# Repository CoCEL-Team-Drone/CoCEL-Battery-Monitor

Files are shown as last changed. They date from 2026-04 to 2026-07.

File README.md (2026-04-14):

# CoCEL LiPo Battery Monitor



**A high-current LiPo battery monitor with individual cell voltage sensing**

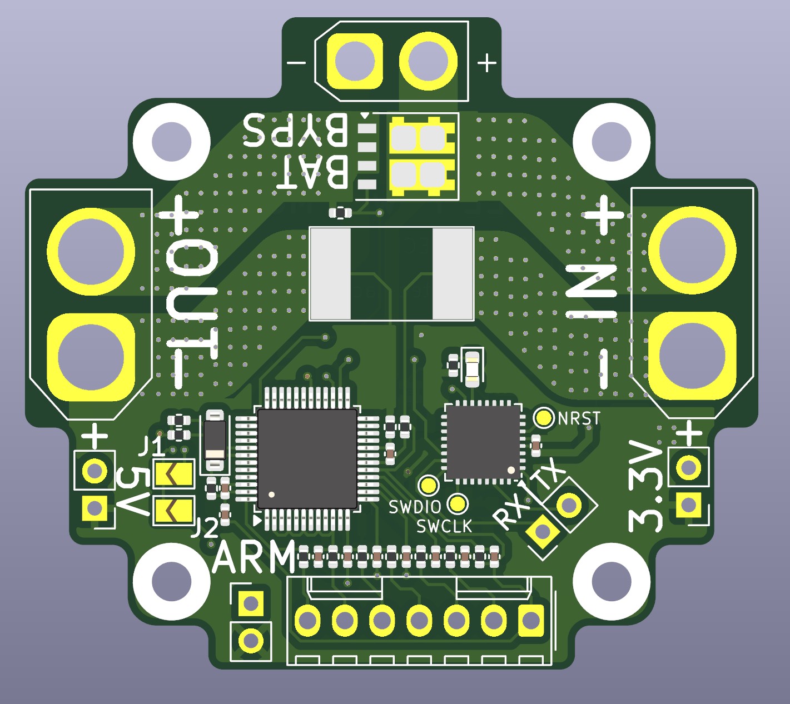
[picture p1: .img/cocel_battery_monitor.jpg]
CoCEL Battery Monitor Image


[!IMPORTANT] 
This project is currently under development! Especially cell voltage monitoring circuit. Please stay tuned for future updates.

The CoCEL LiPo Battery Monitor is a dedicated power management and monitoring solution for multicopters. It measures total pack voltage, discharge current, and individual cell voltages, interfacing with a FC via UART.

## 1. Core Specifications

### Power
- **Voltage:** 4s~6s LiPo (14.8 V ~ 25.2 V)
- **Current:** 200 A continuous
- **Output Cutoff:** Main power output can be cut off via a physical arming switch (shorting pins) or via UART commands
- **Aux Power Output:**
    - 3.3 V (3 A)
    - 5 V (3 A)
    - Input Bypass: Dedicated power rail for an SBC (remains active even when the main output is cut off)

### Connectivity
- **Interfaces:** 
    - **Communication:** 1x UART
    - **Visual Feedback:** 1x Diagnostic LED
    - **Firmware update:** Test points are used for firmware updates (SWDIO, SWCLK, NRST).

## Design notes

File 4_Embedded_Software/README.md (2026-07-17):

# Embedded Software
Implemented by Sanghyun Park and Eunseon Choi.

## API
### Overview
1. System initialization
2. BQ initialization
3. Ready for sensing

### Input
```
type def struct
{
    int32_t type;
    int32_t data_1;
    int32_t data_2;
    int32_t data_3;
}UartReceiveData;
```
- Example  
`printf '1 4 10 1\n' > /dev/ttyACM0`

### Output
```
typedef struct
{
	uint32_t timestamp;
	uint32_t read_out_time;
	int16_t status;
	uint16_t data_1;
	uint16_t data_2;
	uint16_t data_3;
	uint16_t data_4;
	uint16_t data_5;
	uint16_t data_6;
	uint16_t data_7;
	int16_t data_etc_1;
	int16_t data_etc_2;
}UartTransmitData;
```
- Example  
`1000,5,0,2453,3534,4353,3452,1379,997,234`

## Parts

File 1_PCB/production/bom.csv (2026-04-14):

Designator | Footprint | Quantity | Value | LCSC Part #
C1, C2, C3, C4, C5, C6, C7 | 0402 | 7 | 0.22uF
C10, C14 | 0402 | 2 | 0.1uF
C15, C17, C22, C23 | 0603 | 4 | 0.1uF
C16, C21 | 1210 | 2 | 10uF
C18, C24 | 0402 | 2 | 6.8nF
C19, C20, C25, C26 | 1210 | 4 | 22uF
C8 | 0402 | 1 | 1uF
C9 | 0402 | 1 | 0.47uF
D1 | D_SOD-123 | 1 | S1AFL
D2 | 0603 | 1 | LED
JP1, JP2 | SolderJumper-2_P1.3mm_Open_TrianglePad1.0x1.5mm | 2 | Jumper_2_Small_Open
L1 | L_7.3x7.3_H4.5 | 1 | 4.7uH
L2 | L_7.3x7.3_H4.5 | 1 | 3.3uH
Q1 | ST_PowerFLAT-6L_5x6mm_P1.27mm | 1 | STL325N4LF8AG
R1, R2, R3, R4, R5, R6, R7 | 0402 | 7 | 47
R10, R11, R22, R8 | 0402 | 4 | 100
R12 | 3920 | 1 | 0.001
R13, R17, R21, R26, R27 | 0402 | 5 | 10k
R14 | 0402 | 1 | 430k
R15 | 0402 | 1 | 82k
R18 | 0402 | 1 | 6.8k
R19 | 0402 | 1 | 75k
R20 | 0402 | 1 | 24k
R9 | 0402 | 1 | 1M
U1 | TQFP-48_7x7mm_P0.5mm | 1 | BQ76942
U2 | QFN-32-1EP_5x5mm_P0.5mm_EP3.45x3.45mm | 1 | STM32G031K8Ux
U3, U4 | HTSOP-8-1EP_3.9x4.9mm_P1.27mm_EP2.4x3.2mm | 2 | BD9E302EFJ

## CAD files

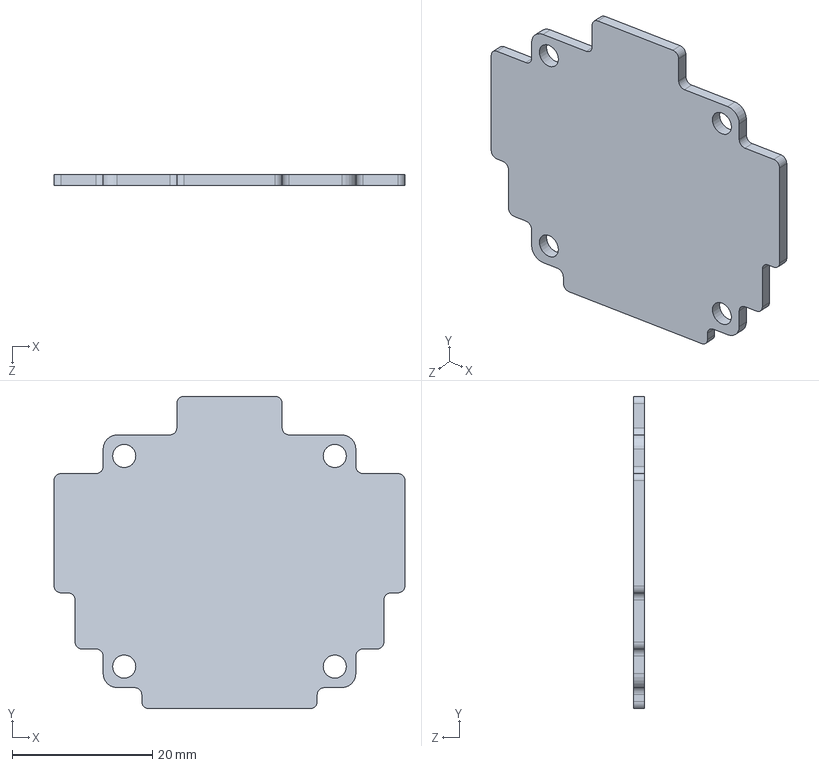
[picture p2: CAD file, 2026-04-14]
2_CAD/CoCEL_PowerMonitir_PCB.SLDPRT
50.0 x 44.5 x 1.60 mm

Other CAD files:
2_CAD/CoCEL_PowerMonitir_PCB.DXF

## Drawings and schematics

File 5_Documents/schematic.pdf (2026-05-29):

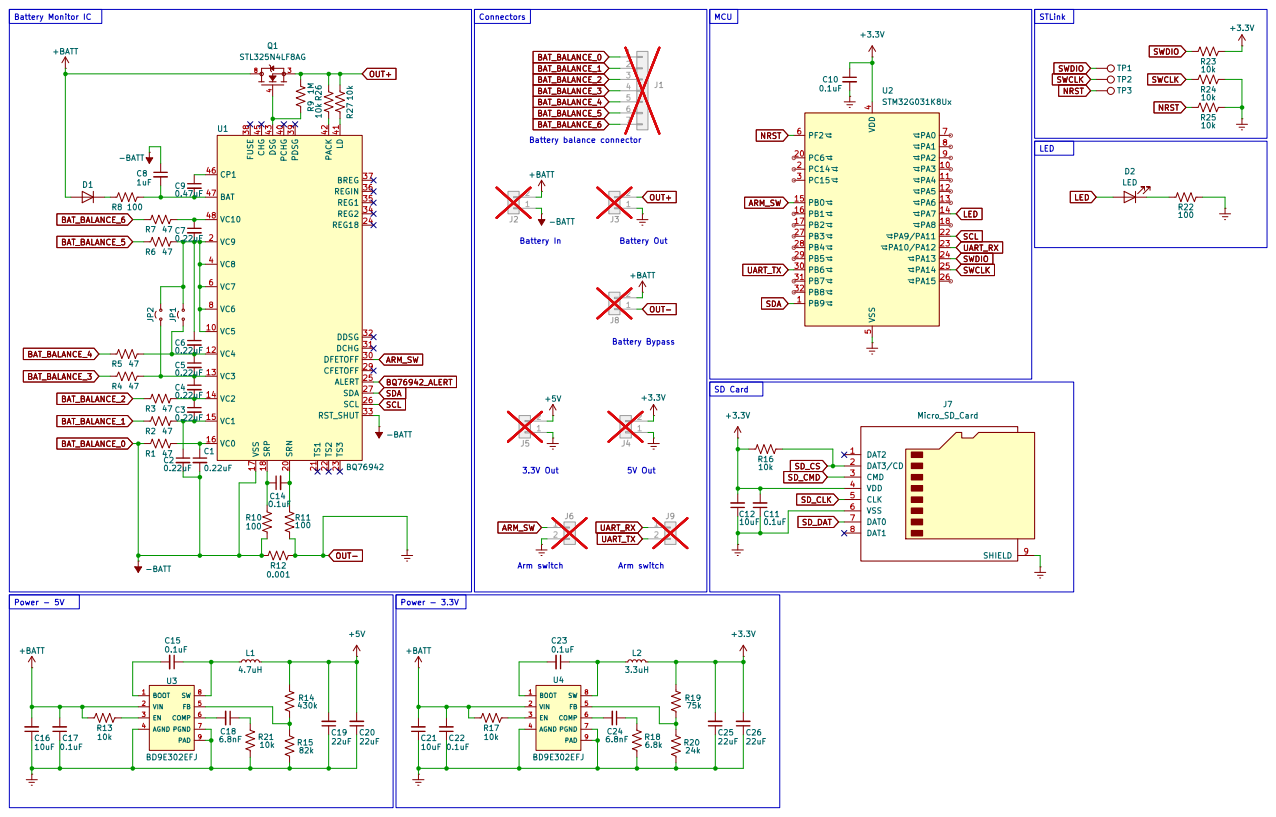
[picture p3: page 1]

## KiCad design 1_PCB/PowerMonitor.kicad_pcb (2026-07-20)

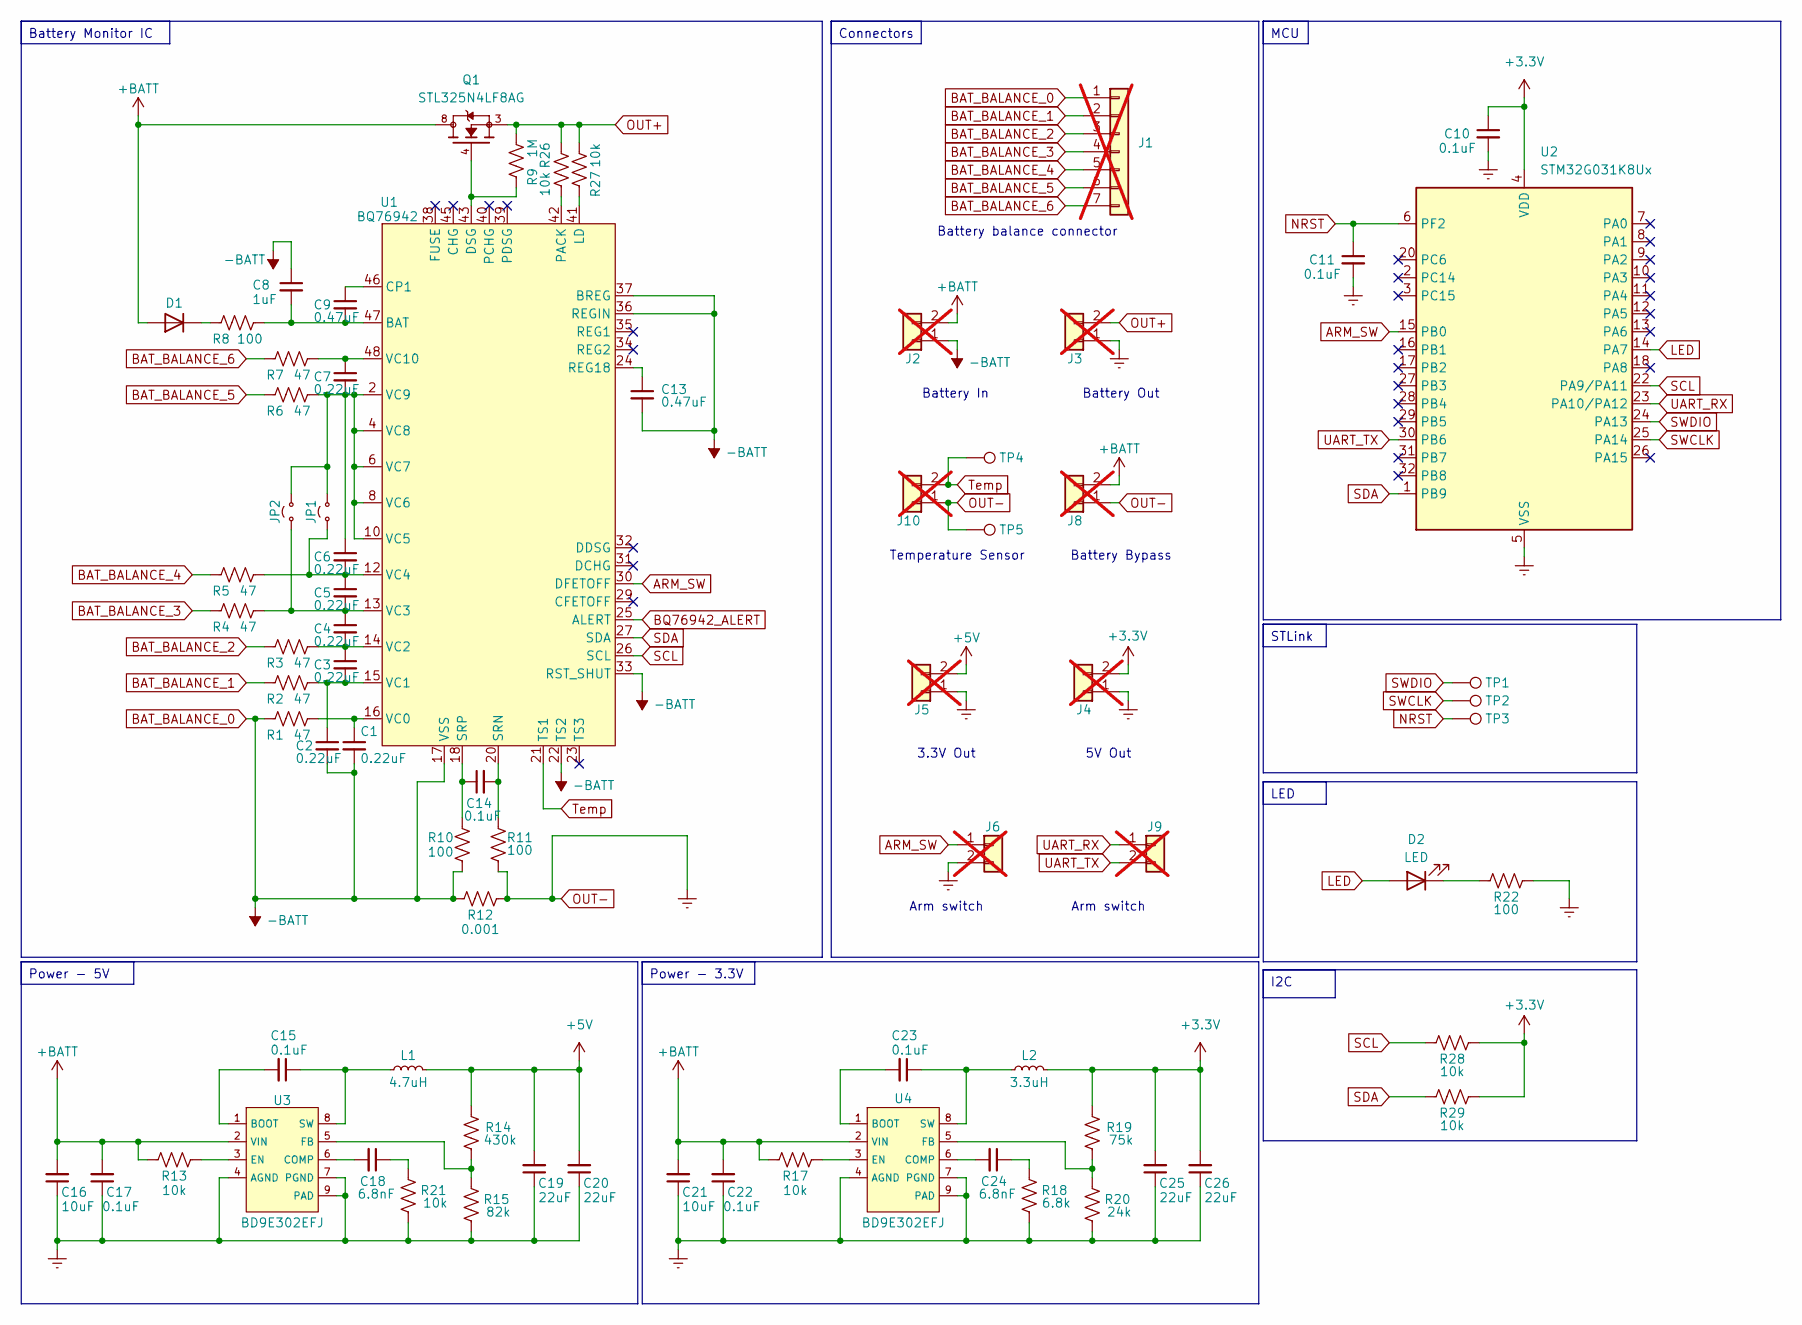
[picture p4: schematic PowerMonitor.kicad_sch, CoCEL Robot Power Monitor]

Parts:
C1, C2, C3, C4, C5, C6, C7: 0.22uF; C_0402_1005Metric
C8: 1uF; C_0402_1005Metric
C9, C13: 0.47uF; C_0402_1005Metric
C10, C11, C14: 0.1uF; C_0402_1005Metric
C15, C17, C22, C23: 0.1uF; C_0603_1608Metric
C16, C21: 10uF; C_1210_3225Metric
C18, C24: 6.8nF; C_0402_1005Metric_Pad0.74x0.62mm_HandSolder
C19, C20, C25, C26: 22uF; C_1210_3225Metric
D1: S1AFL; D_SOD-123
D2: LED; LED_0603_1608Metric
J1: Conn_01x07; Molex_KK-254_AE-6410-07A_1x07_P2.54mm_Vertical; not fitted
J2: Conn_01x02; AMASS_XT60-M_1x02_P7.20mm_Vertical; not fitted
J3: Conn_01x02; AMASS_XT60-F_1x02_P7.20mm_Vertical; not fitted
J4, J5, J6, J9, J10: Conn_01x02; PinHeader_1x02_P2.54mm_Vertical; not fitted
J8: Conn_01x02; AMASS_XT30U-F_1x02_P5.0mm_Vertical; not fitted
JP1, JP2: Jumper_2_Small_Open; SolderJumper-2_P1.3mm_Open_TrianglePad1.0x1.5mm
L1: 4.7uH; L_7.3x7.3_H4.5
L2: 3.3uH; L_7.3x7.3_H4.5
Q1: STL325N4LF8AG; ST_PowerFLAT-6L_5x6mm_P1.27mm
R1, R2, R3, R4, R5, R6, R7: 47; R_0402_1005Metric
R8, R10, R11, R22: 100; R_0402_1005Metric
R9: 1M; R_0402_1005Metric
R12: 0.001; R_3920_10052Metric
R13, R17, R21, R26, R27, R28, R29: 10k; R_0402_1005Metric
R14: 430k; R_0402_1005Metric
R15: 82k; R_0402_1005Metric
R18: 6.8k; R_0402_1005Metric
R19: 75k; R_0402_1005Metric
R20: 24k; R_0402_1005Metric
TP1, TP2, TP3, TP4, TP5: TestPoint; TestPoint_Pad_D1.0mm
U1: BQ76942; TQFP-48_7x7mm_P0.5mm
U2: STM32G031K8Ux; QFN-32-1EP_5x5mm_P0.5mm_EP3.45x3.45mm
U3, U4: BD9E302EFJ; HTSOP-8-1EP_3.9x4.9mm_P1.27mm_EP2.4x3.2mm

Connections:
+3.3V: C10.1, C25.2, C26.2, J4.2, L2.2, R19.2, R28.2, R29.2, U2.4 (VDD)
+5V: C19.2, C20.2, J5.2, L1.2, R14.2
+BATT: C16.2, C17.2, C21.2, C22.2, D1.2 (A), J2.2, J8.2, Q1.5, Q1.6, Q1.7, Q1.8, R13.1, R17.1, U3.2 (VIN), U4.2 (VIN)
ARM_SW: J6.1, U1.30 (DFETOFF), U2.15 (PB0)
BAT_BALANCE_0: C1.2, C2.2, C8.1, C13.2, J1.1, J2.1, R1.1, R10.2, R12.2, U1.17 (VSS), U1.22 (TS2), U1.33 (RST_SHUT), U1.36 (REGIN), U1.37 (BREG)
BAT_BALANCE_1: J1.2, R2.1
BAT_BALANCE_2: J1.3, R3.1
BAT_BALANCE_3: J1.4, R4.1
BAT_BALANCE_4: J1.5, R5.1
BAT_BALANCE_5: J1.6, R6.1
BAT_BALANCE_6: J1.7, R7.1
BQ76942_ALERT: U1.25 (ALERT)
LED: D2.2 (A), U2.14 (PA7)
NRST: C11.1, TP3.1 (1_1), U2.6 (PF2)
unnamed: C18.1, R21.2
unnamed: C24.1, R18.2
unnamed: D1.1 (K), R8.1
unnamed: D2.1 (K), R22.1
unnamed: C5.1, C6.2, JP1.1 (A), R5.2, U1.12 (VC4)
unnamed: C6.1, C7.2, JP1.2 (B), JP2.2 (B), R6.2, U1.2 (VC9), U1.4 (VC8), U1.6 (VC7), U1.8 (VC6), U1.10 (VC5)
unnamed: C4.1, C5.2, JP2.1 (A), R4.2, U1.13 (VC3)
unnamed: C8.2, C9.2, R8.2, U1.47 (BAT)
unnamed: C9.1, U1.46 (CP1)
unnamed: Q1.4, R9.1, U1.43 (DSG)
unnamed: R27.1, U1.41 (LD)
unnamed: R26.2, U1.42 (PACK)
unnamed: C13.1, U1.24 (REG18)
unnamed: C14.2, R11.2, U1.20 (SRN)
unnamed: C14.1, R10.1, U1.18 (SRP)
unnamed: C1.1, R1.2, U1.16 (VC0)
unnamed: C2.1, C3.2, R2.2, U1.15 (VC1)
unnamed: C3.1, C4.2, R3.2, U1.14 (VC2)
unnamed: C7.1, R7.2, U1.48 (VC10)
unnamed: C15.2, U3.1 (BOOT)
unnamed: C18.2, U3.6 (COMP)
unnamed: R13.2, U3.3 (EN)
unnamed: R14.1, R15.2, U3.5 (FB)
unnamed: C15.1, L1.1, U3.8 (SW)
unnamed: C23.2, U4.1 (BOOT)
unnamed: C24.2, U4.6 (COMP)
unnamed: R17.2, U4.3 (EN)
unnamed: R19.1, R20.2, U4.5 (FB)
unnamed: C23.1, L2.1, U4.8 (SW)
OUT+: J3.2, Q1.1, Q1.2, Q1.3, R9.2, R26.1, R27.2
OUT-: C10.2, C11.2, C16.1, C17.1, C19.1, C20.1, C21.1, C22.1, C25.1, C26.1, J3.1, J4.1, J5.1, J6.2, J8.1, J10.1, R11.1, R12.1, R15.1, R18.1, R20.1, R21.1, R22.2, TP5.1 (1_1), U2.5 (VSS), U2.33 (VSS), U3.4 (AGND), U3.7 (PGND), U3.9 (PAD), U4.4 (AGND), U4.7 (PGND), U4.9 (PAD)
SCL: R28.1, U1.26 (SCL), U2.22 (PA9/PA11)
SDA: R29.1, U1.27 (SDA), U2.1 (PB9)
SWCLK: TP2.1 (1_1), U2.25 (PA14)
SWDIO: TP1.1 (1_1), U2.24 (PA13)
Temp: J10.2, TP4.1 (1_1), U1.21 (TS1)
UART_RX: J9.1, U2.23 (PA10/PA12)
UART_TX: J9.2, U2.30 (PB6)

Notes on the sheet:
Battery balance connector
Temperature Sensor
Arm switch
Battery Bypass
Battery Out
Battery In
5V Out
3.3V Out
Battery Monitor IC
STLink
LED
Power - 5V
Connectors
I2C
Power - 3.3V
MCU

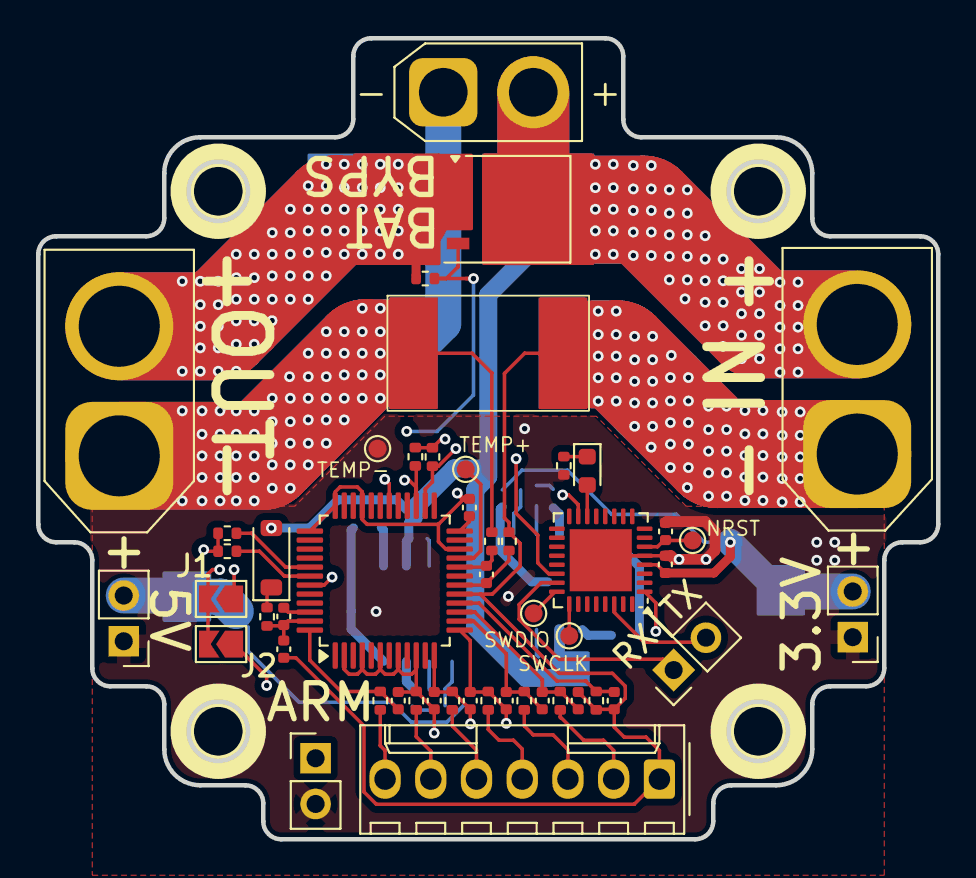
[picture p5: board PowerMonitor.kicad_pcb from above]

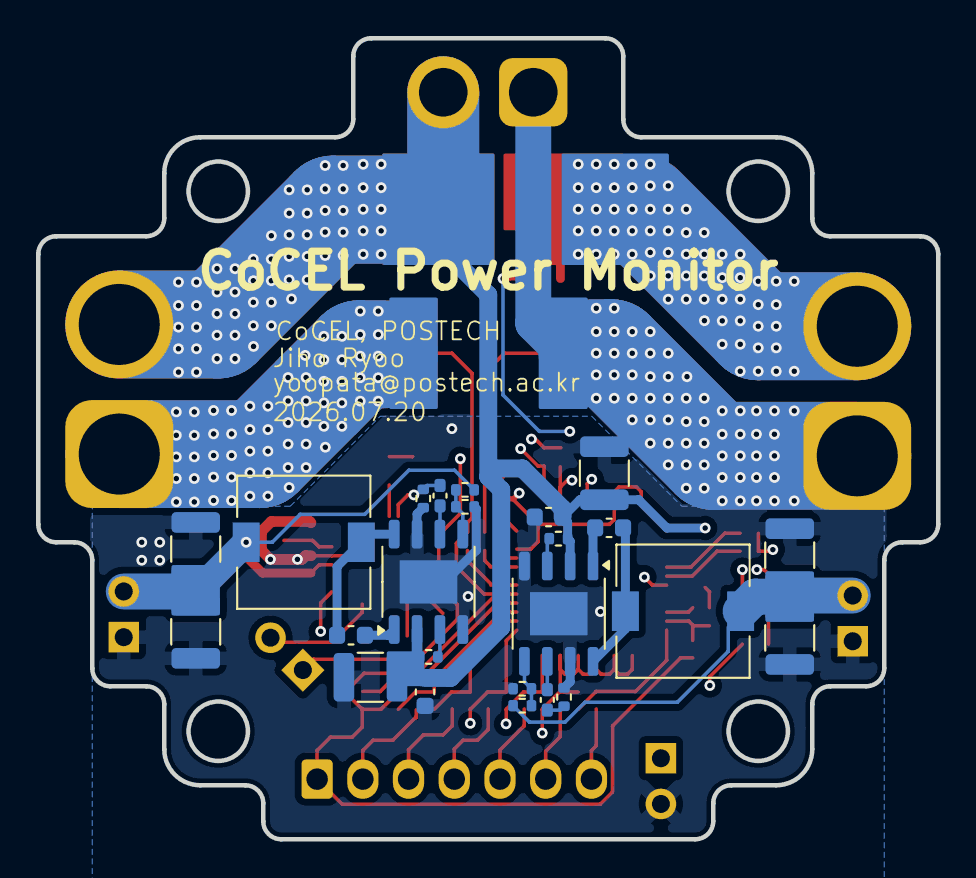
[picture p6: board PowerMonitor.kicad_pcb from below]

Board: 4 copper layers, 50.0 x 44.5 mm, 74 parts (24 on the bottom side), 51 nets.

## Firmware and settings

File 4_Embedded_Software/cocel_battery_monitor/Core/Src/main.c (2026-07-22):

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
/* Includes ------------------------------------------------------------------*/
#include "main.h"

/* USER CODE BEGIN Includes */
#include <stdio.h>
#include <inttypes.h>
/* USER CODE END Includes */

/* USER CODE BEGIN PD */

/*
============================================================
					  Memory Address
============================================================
*/
#define BQ76942_ADDR  0x10

#define DM_VCELL_MODE       0x9304 // Vcell mode

// CONFIG_UPDATE mode
#define BATT_STATUS_REG     0x12
#define BATT_CFGUPDATE      0x0001

// Protection
#define DM_ENABLED_PROT_A      0x9261
#define DM_ENABLED_PROT_B      0x9262
#define DM_ENABLED_PROT_C      0x9263

// Cell balancing
#define DM_BALANCING_CONFIGURATION   0x9335

// Enable ARM_SW
#define DM_DFETOFF_PIN_CONFIG    0x92FB

// Enable TS1, TS3 thermistor
#define DM_TS1_CONFIG    0x92FD
#define DM_TS3_CONFIG    0x92FFU

#define UART_TX_BUF_SIZE 128U
#define UART_RX_BUF_SIZE 64

/*
============================================================
						Command
============================================================
*/
// CONFIG_UPDATE mode
#define CMD_SET_CFGUPDATE   0x0090
#define CMD_EXIT_CFGUPDATE  0x0092

// FET control
#define CMD_FET_ENABLE            0x0022
#define CMD_MANUFACTURING_STATUS  0x0057
#define CMD_ALL_FETS_ON           0x0096
#define MFG_STATUS_FET_EN_MASK    0x0010

/* USER CODE END PD */

I2C_HandleTypeDef hi2c1;

TIM_HandleTypeDef htim2;

UART_HandleTypeDef huart1;

/* USER CODE BEGIN PV */
typedef struct
{
	uint32_t timestamp;
	uint32_t read_out_time;
	uint16_t cell1;
	uint16_t cell2;
	uint16_t cell3;
	uint16_t cell4;
	uint16_t cell5;
	uint16_t cell6;

	uint16_t stack_voltage_raw;

	int16_t  current_raw;
	int16_t  ext_temp_raw;
} BattRawData;

// for connect timer interrupt <-> while loop
volatile uint8_t TI_SENSOR_RECORD_FLAG = 0;
volatile uint8_t TI_UART_TRANSMIT_FLAG = 0;

volatile BattRawData batt_data;

volatile uint16_t cell1, cell2, cell3, cell4, cell5, cell6;
volatile uint16_t stack_voltage_raw;
volatile int16_t current_raw;
volatile int16_t int_temp_raw;

volatile HAL_StatusTypeDef i2c_status;
volatile uint32_t i2c_error;
volatile HAL_StatusTypeDef bq_ready;


/*
============================================================
				    For UART Interface - START
============================================================
*/
// for system initialization
volatile uint8_t IS_INITIALIZED = 0;
volatile uint8_t CELL_NUM = 4;
volatile uint8_t SET_HZ = 10;
volatile uint8_t TI_HZ_MAX_CNT = 0;
volatile uint8_t TEMP_UNIT = 1; // K, C
// for system operation
volatile uint8_t EX_RECORD_FLAG = 0;
volatile uint8_t ARM_STATUS = 0;

// transmit data format
typedef struct
{
	uint32_t timestamp;
	uint32_t read_out_time;
	int16_t status;
	uint16_t data_1;
	uint16_t data_2;
	uint16_t data_3;
	uint16_t data_4;
	uint16_t data_5;
	uint16_t data_6;
	uint16_t data_7;
	int16_t data_etc_1;
	int16_t data_etc_2;
}UartTransmitData;

// receive data format
typedef struct
{
	int32_t type;
	int32_t data_1;
	int32_t data_2;
	int32_t data_3;
}UartReceiveData;

volatile UartTransmitData data_transmit;
volatile UartReceiveData data_receive;

UartTransmitData data_transmit_for_warning;

// for receive
volatile uint8_t data_receive_ready = 0;
volatile uint8_t uart_parse_error = 0;
static uint8_t uart_rx_byte;
static char uart_build_buffer[UART_RX_BUF_SIZE];
static uint16_t uart_build_index = 0;
static char uart_line_buffer[UART_RX_BUF_SIZE];
static volatile uint8_t uart_line_ready = 0;

/*
============================================================
				    For UART Interface - END
============================================================
*/

/* USER CODE END PV */

void SystemClock_Config(void);
static void MX_GPIO_Init(void);
static void MX_I2C1_Init(void);
static void MX_USART1_UART_Init(void);
static void MX_TIM2_Init(void);
/* USER CODE BEGIN PFP */

// Direct command read functions
HAL_StatusTypeDef BQ_ReadReg(uint8_t reg, uint8_t *data, uint16_t len);
HAL_StatusTypeDef BQ_ReadU8(uint8_t reg, uint8_t *value);
HAL_StatusTypeDef BQ_ReadU16(uint8_t reg, uint16_t *value);
HAL_StatusTypeDef BQ_ReadI16(uint8_t reg, int16_t *value);

// Data Memory read/write functions
HAL_StatusTypeDef BQ_WriteDataMemoryU8(uint16_t addr, uint8_t value);
HAL_StatusTypeDef BQ_ReadDataMemoryU8(uint16_t addr, uint8_t *value);
HAL_StatusTypeDef BQ_WriteDataMemoryU16(uint16_t addr, uint16_t value);
HAL_StatusTypeDef BQ_ReadDataMemoryU16(uint16_t addr, uint16_t *value);

// BQ76942 configuration functions
HAL_StatusTypeDef BQ_SetVcellMode(uint8_t cell_count);
HAL_StatusTypeDef BQ_DisableCellBalancing(void);
HAL_StatusTypeDef BQ_DisableProtections(void);
HAL_StatusTypeDef BQ_EnableFETs(void);
HAL_StatusTypeDef BQ_SetDFETOFFPin(void);
HAL_StatusTypeDef BQ_SetTS1Thermistor(void);
HAL_StatusTypeDef BQ_SetTS3Thermistor(void);

// Subcommand / command helper functions
HAL_StatusTypeDef BQ_ReadSubcommandU16(uint16_t subcmd, uint16_t *value);
HAL_StatusTypeDef BQ_WriteSubcommand(uint16_t subcmd);
uint8_t BQ_Checksum(uint16_t addr, uint8_t *data, uint8_t len);
uint8_t BQ_WaitCfgUpdate(uint8_t enter);
HAL_StatusTypeDef BQ_WaitCfgUpdate(uint8_t enter);

// get data
HAL_StatusTypeDef BQ_ReadBattRawData(BattRawData *data);

// Debug / UART helper functions
void UART_Print(char *msg);
void UART_TransmitParsedData(const UartTransmitData *tx_data);
void clear_tx_data(UartTransmitData *tx_data);
HAL_StatusTypeDef UART_GetReceiveData(UartReceiveData *output);

/* USER CODE END PFP */

/* USER CODE BEGIN 0 */

/* ============================================================
 * Direct Command Read Functions
 * ============================================================ */
// common read
HAL_StatusTypeDef BQ_ReadReg(uint8_t reg, uint8_t *data, uint16_t len)
{
    HAL_StatusTypeDef status;

    if ((data == NULL) || (len == 0U)) return HAL_ERROR;

    status = HAL_I2C_Mem_Read(
        &hi2c1,
        BQ76942_ADDR,
        reg,
        I2C_MEMADD_SIZE_8BIT,
        data,
        len,
        100
    );

    i2c_status = status;
    i2c_error = HAL_I2C_GetError(&hi2c1);

    return status;
}
// read unsigned 8bit
HAL_StatusTypeDef BQ_ReadU8(uint8_t reg, uint8_t *value)
{
    if (value == NULL)return HAL_ERROR;
    return BQ_ReadReg(reg, value, 1);
}
// read unsigned 16bit
HAL_StatusTypeDef BQ_ReadU16(uint8_t reg, uint16_t *value)
{
    uint8_t data[2];
    HAL_StatusTypeDef status;

    if (value == NULL)return HAL_ERROR;

    status = BQ_ReadReg(reg, data, 2);

    if (status != HAL_OK)return status;

    *value = (uint16_t)data[0] | ((uint16_t)data[1] << 8);

    return HAL_OK;
}
// read signed 16bit
HAL_StatusTypeDef BQ_ReadI16(uint8_t reg, int16_t *value)
{
    uint8_t data[2];
    uint16_t raw;
    HAL_StatusTypeDef status;

    if (value == NULL)return HAL_ERROR;

    status = BQ_ReadReg(reg, data, 2);

    if (status != HAL_OK)return status;

    raw = (uint16_t)data[0] | ((uint16_t)data[1] << 8);

    *value = (int16_t)raw;

    return HAL_OK;
}

/* ============================================================
 * Data Memory Read / Write Functions
 * ============================================================ */
HAL_StatusTypeDef BQ_WriteDataMemoryU8(uint16_t addr, uint8_t value)
{
    uint8_t addr_buf[2];
    uint8_t data_buf[1];
    uint8_t chk_len[2];

    HAL_StatusTypeDef status;

    addr_buf[0] = (uint8_t)(addr & 0xFFU);
    addr_buf[1] = (uint8_t)(addr >> 8);

    data_buf[0] = value;

    chk_len[0] = BQ_Checksum(addr, data_buf, 1);
    chk_len[1] = 5U;

    status = HAL_I2C_Mem_Write(
        &hi2c1,
        BQ76942_ADDR,
        0x3E,
        I2C_MEMADD_SIZE_8BIT,
        addr_buf,
        2,
        100
    );

    if (status != HAL_OK) return status;
    HAL_Delay(2);

    status = HAL_I2C_Mem_Write(
        &hi2c1,
        BQ76942_ADDR,
        0x40,
        I2C_MEMADD_SIZE_8BIT,
        data_buf,
        1,
        100
    );

    if (status != HAL_OK) return status;
    HAL_Delay(2);


    status = HAL_I2C_Mem_Write(
        &hi2c1,
        BQ76942_ADDR,
        0x60,
        I2C_MEMADD_SIZE_8BIT,
        chk_len,
        2,
        100
    );

    if (status != HAL_OK) return status;
    HAL_Delay(10);

    return HAL_OK;
}

HAL_StatusTypeDef BQ_ReadDataMemoryU8(uint16_t addr, uint8_t *value)
{
    uint8_t addr_buf[2];

    HAL_StatusTypeDef status;

    if (value == NULL) return HAL_ERROR;

    addr_buf[0] = (uint8_t)(addr & 0xFFU);
    addr_buf[1] = (uint8_t)(addr >> 8);

    status = HAL_I2C_Mem_Write(
        &hi2c1,
        BQ76942_ADDR,
        0x3E,
        I2C_MEMADD_SIZE_8BIT,
        addr_buf,
        2,
        100
    );

    if (status != HAL_OK) return status;
    HAL_Delay(10);

    status = HAL_I2C_Mem_Read(
        &hi2c1,
        BQ76942_ADDR,
        0x40,
        I2C_MEMADD_SIZE_8BIT,
        value,
        1,
        100
    );

    return status;
}

HAL_StatusTypeDef BQ_WriteDataMemoryU16(uint16_t addr, uint16_t value)
{
    uint8_t addr_buf[2];
    uint8_t data_buf[2];
    uint8_t chk_len[2];

    HAL_StatusTypeDef status;

    addr_buf[0] = (uint8_t)(addr & 0xFFU);
    addr_buf[1] = (uint8_t)(addr >> 8);

    data_buf[0] = (uint8_t)(value & 0xFFU);
    data_buf[1] = (uint8_t)(value >> 8);

    chk_len[0] = BQ_Checksum(addr, data_buf, 2);
    chk_len[1] = 6U;

    status = HAL_I2C_Mem_Write(
        &hi2c1,
        BQ76942_ADDR,
        0x3E,
        I2C_MEMADD_SIZE_8BIT,
        addr_buf,
        2,
        100
    );

    if (status != HAL_OK) return status;
    HAL_Delay(2);

    status = HAL_I2C_Mem_Write(
        &hi2c1,
        BQ76942_ADDR,
        0x40,
        I2C_MEMADD_SIZE_8BIT,
        data_buf,
        2,
        100
    );

    if (status != HAL_OK) return status;
    HAL_Delay(2);

    status = HAL_I2C_Mem_Write(
        &hi2c1,
        BQ76942_ADDR,
        0x60,
        I2C_MEMADD_SIZE_8BIT,
        chk_len,
        2,
        100
    );

    if (status != HAL_OK) return status;
    HAL_Delay(10);

    return HAL_OK;
}

HAL_StatusTypeDef BQ_ReadDataMemoryU16(uint16_t addr, uint16_t *value)
{
    uint8_t addr_buf[2];
    uint8_t data_buf[2];

    HAL_StatusTypeDef status;

    if (value == NULL) return HAL_ERROR;

    addr_buf[0] = (uint8_t)(addr & 0xFFU);
    addr_buf[1] = (uint8_t)(addr >> 8);

    status = HAL_I2C_Mem_Write(
        &hi2c1,
        BQ76942_ADDR,
        0x3E,
        I2C_MEMADD_SIZE_8BIT,
        addr_buf,
        2,
        100
    );

    if (status != HAL_OK) return status;
    HAL_Delay(10);

    status = HAL_I2C_Mem_Read(
        &hi2c1,
        BQ76942_ADDR,
        0x40,
        I2C_MEMADD_SIZE_8BIT,
        data_buf,
        2,
        100
    );

    if (status != HAL_OK) return status;

    *value =
        (uint16_t)data_buf[0] |
        ((uint16_t)data_buf[1] << 8);

    return HAL_OK;
}
/* ============================================================
 * BQ76942 Configuration Functions
 * ============================================================ */
HAL_StatusTypeDef BQ_DisableProtections(void)
{
    uint8_t pa = 0U;
    uint8_t pb = 0U;
    uint8_t pc = 0U;

    char buf[120];

    if (BQ_WriteSubcommand(CMD_SET_CFGUPDATE) != HAL_OK)
    {
//    	UART_Print("BQ_WriteSubcommand\r\n");
    	return HAL_ERROR;
    }

    if (BQ_WaitCfgUpdate(1) != HAL_OK)
    {
//        UART_Print("CFGUPDATE enter failed\r\n");
        return HAL_ERROR;
    }


    if (BQ_WriteDataMemoryU8(
            DM_ENABLED_PROT_A,
            0x00) != HAL_OK)
    {
        return HAL_ERROR;
    }

    if (BQ_WriteDataMemoryU8(
            DM_ENABLED_PROT_B,
            0x00) != HAL_OK)
    {
        return HAL_ERROR;
    }

    if (BQ_WriteDataMemoryU8(
            DM_ENABLED_PROT_C,
            0x00) != HAL_OK)
    {
        return HAL_ERROR;
    }


    if (BQ_ReadDataMemoryU8(
            DM_ENABLED_PROT_A,
            &pa) != HAL_OK)
    {
        return HAL_ERROR;
    }

    if (BQ_ReadDataMemoryU8(
            DM_ENABLED_PROT_B,
            &pb) != HAL_OK)
    {
        return HAL_ERROR;
    }

    if (BQ_ReadDataMemoryU8(
            DM_ENABLED_PROT_C,
            &pc) != HAL_OK)
    {
        return HAL_ERROR;
    }

//    snprintf(
//        buf,
//        sizeof(buf),
//        "Protection RB PA=0x%02X PB=0x%02X PC=0x%02X\r\n",
//        pa,
//        pb,
//        pc
//    );
//
//    UART_Print(buf);

    BQ_WriteSubcommand(CMD_EXIT_CFGUPDATE);

    if (BQ_WaitCfgUpdate(0U) != HAL_OK)
    {
//        UART_Print("CFGUPDATE exit failed\r\n");
        return HAL_ERROR;
    }

    return HAL_OK;
}

// Vcell Mode setting
HAL_StatusTypeDef BQ_SetVcellMode(uint8_t cell_count)
{
	uint16_t mode;
	uint16_t rb = 0U;
	char buf[120];

	if (cell_count == 4U)
	{
		mode = 0x000F; // Cell1~Cell4 enabled
	}
	else if (cell_count == 6U)
	{
		mode = 0x030F; // Cell1~4,Cell9~10 // mode = 0x003F; // Cell1~Cell6 enabled
	}
	else
	{
		return HAL_ERROR;
	}


	if (BQ_WriteSubcommand(CMD_SET_CFGUPDATE) != HAL_OK)
	{
		return HAL_ERROR;
	}

	if (BQ_WaitCfgUpdate(1U) != HAL_OK)
	{
//		UART_Print("CFGUPDATE enter failed\r\n");
		return HAL_ERROR;
	}


	if (BQ_WriteDataMemoryU16(
			DM_VCELL_MODE,
			mode) != HAL_OK)
	{
		return HAL_ERROR;
	}


	if (BQ_ReadDataMemoryU16(
			DM_VCELL_MODE,
			&rb) != HAL_OK)
	{
		return HAL_ERROR;
	}


	if (rb != mode)
	{
//		UART_Print("VcellMode verify failed\r\n");
		return HAL_ERROR;
	}


//	snprintf(
//		buf,
//		sizeof(buf),
//		"VcellMode set=0x%04X readback=0x%04X\r\n",
//		mode,
//		rb
//	);
//
//	UART_Print(buf);


	if (BQ_WriteSubcommand(CMD_EXIT_CFGUPDATE) != HAL_OK)
	{
		return HAL_ERROR;
	}

	if (BQ_WaitCfgUpdate(0U) != HAL_OK)
	{
//		UART_Print("CFGUPDATE exit failed\r\n");
		return HAL_ERROR;
	}

	return HAL_OK;
}

// disable cell balanceing
HAL_StatusTypeDef BQ_DisableCellBalancing(void)
{
    uint8_t rb = 0U;

    if(BQ_WriteSubcommand(CMD_SET_CFGUPDATE)!=HAL_OK)
    {
//    	UART_Print("BQ_DisableCellBalancing-0 Error\r\n");
        return HAL_ERROR;
    }

    if (BQ_WaitCfgUpdate(1)!= HAL_OK)
    {
//    	UART_Print("BQ_DisableCellBalancing-1 Error\r\n");
        return HAL_ERROR;
    }


    if (BQ_WriteDataMemoryU8(
            DM_BALANCING_CONFIGURATION,
            0x10) != HAL_OK)
    {
//    	UART_Print("BQ_DisableCellBalancing-2 Error\r\n");
        return HAL_ERROR;
    }


    if (BQ_ReadDataMemoryU8(
            DM_BALANCING_CONFIGURATION,
            &rb) != HAL_OK)
    {
//    	UART_Print("BQ_DisableCellBalancing-3 Error\r\n");
        return HAL_ERROR;
    }


    if (rb != 0x10U)
    {
//    	UART_Print("BQ_DisableCellBalancing-4 Error\r\n");
        return HAL_ERROR;
    }


    BQ_WriteSubcommand(CMD_EXIT_CFGUPDATE);

    if (BQ_WaitCfgUpdate(0)!= HAL_OK)
    {
//    	UART_Print("BQ_DisableCellBalancing-5 Error\r\n");
        return HAL_ERROR;
    }

    return HAL_OK;
}

// Enable DFETOFF pin(ARM SW)
HAL_StatusTypeDef BQ_SetDFETOFFPin(void)
{
    uint8_t rb = 0U;

    /* Enter CONFIG_UPDATE */
    if (BQ_WriteSubcommand(CMD_SET_CFGUPDATE) != HAL_OK)
    {
        return HAL_ERROR;
    }

    if (BQ_WaitCfgUpdate(1U) != HAL_OK)
    {
        return HAL_ERROR;
    }


    /* DFETOFF function, active-low */
    if (BQ_WriteDataMemoryU8(
            DM_DFETOFF_PIN_CONFIG,
            0x82U) != HAL_OK)
    {
        return HAL_ERROR;
    }


    /* Readback */
    if (BQ_ReadDataMemoryU8(
            DM_DFETOFF_PIN_CONFIG,
            &rb) != HAL_OK)
    {
        return HAL_ERROR;
    }
    else
    {
//        char bufd[64];
//
//        sprintf(bufd,
//                 "DFETOFF Config = 0x%02X\r\n",
//                 rb);

//        UART_Print(bufd);
    }

    if (rb != 0x82U)
    {
        return HAL_ERROR;
    }


    /* Exit CONFIG_UPDATE */
    if (BQ_WriteSubcommand(CMD_EXIT_CFGUPDATE) != HAL_OK)
    {
        return HAL_ERROR;
    }

    if (BQ_WaitCfgUpdate(0U) != HAL_OK)
    {
        return HAL_ERROR;
    }

    return HAL_OK;
}

// Enable FET
HAL_StatusTypeDef BQ_EnableFETs(void)
{
    uint16_t mfg_status = 0U;

    if (BQ_ReadSubcommandU16(CMD_MANUFACTURING_STATUS, &mfg_status) != HAL_OK) return HAL_ERROR;

    if ((mfg_status & MFG_STATUS_FET_EN_MASK) == 0U)
    {
    	if(BQ_WriteSubcommand(CMD_FET_ENABLE) != HAL_OK) return HAL_ERROR;
        HAL_Delay(2);
        if (BQ_ReadSubcommandU16(CMD_MANUFACTURING_STATUS, &mfg_status) != HAL_OK) return HAL_ERROR;
        if ((mfg_status & MFG_STATUS_FET_EN_MASK) == 0U) return HAL_ERROR;

    }

    if(BQ_WriteSubcommand(CMD_ALL_FETS_ON) != HAL_OK) return HAL_ERROR;
    HAL_Delay(10);

    return HAL_OK;
}
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
int main(void)
{

  /* MCU Configuration--------------------------------------------------------*/

  /* Reset of all peripherals, Initializes the Flash interface and the Systick. */
  HAL_Init();

  /* Configure the system clock */
  SystemClock_Config();

  /* Initialize all configured peripherals */
  MX_GPIO_Init();
  MX_I2C1_Init();
  MX_USART1_UART_Init();
  MX_TIM2_Init();
  /* USER CODE BEGIN 2 */
  uart_start_status = HAL_UART_Receive_IT(&huart1, &uart_rx_byte, 1);
  bq_ready = HAL_ERROR;
  HAL_TIM_Base_Start_IT(&htim2); // initialize timer interrupt
  HAL_GPIO_WritePin(ARM_SW_GPIO_Port, ARM_SW_Pin, GPIO_PIN_RESET);
  ARM_STATUS = 0;
  HAL_Delay(300);

  clear_tx_data(&data_transmit);
  data_transmit.status = 1;
  data_transmit.data_1 = 1; // initializating

  // wait for initialize
  while(1)
  {
  	if(IS_INITIALIZED == 1)break;

		data_transmit.timestamp = HAL_GetTick();
		data_transmit.data_2 = 1;
		data_transmit.data_3 = 1;
		UART_TransmitParsedData(&data_transmit);

  	HAL_Delay(1000);
  }

  // Initialize sensor module pre-setting
  data_transmit.timestamp = HAL_GetTick();
  data_transmit.data_2 = 2;
  if(BQ_SetVcellMode(CELL_NUM) != HAL_OK)data_transmit.data_3 = 1; //UART_Print("BQ_SerVcellMode Error\r\n");
  if(BQ_DisableCellBalancing() != HAL_OK)data_transmit.data_4 = 1; // UART_Print("BQ_DisableCellBalancing Error\r\n");
  if(BQ_DisableProtections() != HAL_OK)data_transmit.data_5 = 1; // UART_Print("BQ_DisableProtections Error\r\n");
  if(BQ_SetDFETOFFPin() != HAL_OK)data_transmit.data_6 = 1; //UART_Print("BQ_SetDFETOFFPin Error\r\n");
  if(BQ_SetTS1Thermistor() != HAL_OK)data_transmit.data_7 = 1; //UART_Print("BQ_SetTS1Thermistor Error\r\n");
  if(BQ_EnableFETs() != HAL_OK)data_transmit.data_etc_1 = 1; // UART_Print("BQ_EnableFETs Error\r\n");
  UART_TransmitParsedData(&data_transmit);
  HAL_Delay(100);

  // Initialize sensor module
  clear_tx_data(&data_transmit);
  data_transmit.timestamp = HAL_GetTick();
  data_transmit.data_1 = 1;
  bq_ready = HAL_I2C_IsDeviceReady(&hi2c1, BQ76942_ADDR, 3, 100);
  if(bq_ready != HAL_OK)
  {
  	data_transmit.status = 2;
  	data_transmit.data_2 = 1;
  	UART_TransmitParsedData(&data_transmit);
  	return -1;
  }
  data_transmit.status = 1;
  data_transmit.data_2 = 3;
  data_transmit.data_3 = (uint16_t)CELL_NUM;
  data_transmit.data_4 = (uint16_t)SET_HZ;
  data_transmit.data_5 = (uint16_t)TEMP_UNIT;

  UART_TransmitParsedData(&data_transmit);

  /* USER CODE END 2 */

  /* Infinite loop */
  /* USER CODE BEGIN WHILE */
  while (1)
  {
    /* USER CODE END WHILE */

    /* USER CODE BEGIN 3 */
  	if(TI_UART_TRANSMIT_FLAG == 1)
  	{
  		UART_TransmitParsedData(&data_transmit_for_warning);
  		TI_UART_TRANSMIT_FLAG = 0;
  	}

	  if(TI_SENSOR_RECORD_FLAG == 0) continue;
	  TI_SENSOR_RECORD_FLAG = 0;


		//
		clear_tx_data(&data_transmit);

		//
		if(BQ_ReadBattRawData(&batt_data) != HAL_OK)
		{
//			UART_Print("BQ sensor read error\r\n");
			data_transmit.timestamp = batt_data.timestamp;
			data_transmit.status = 1;
			data_transmit.data_1 = 2;
			data_transmit.data_2 = 1;
			data_transmit.data_3 = 1;
			UART_TransmitParsedData(&data_transmit);
			continue;
		}

		uint8_t safety_status = 0U;
		uint8_t fet_status = 0U;

		uint16_t control_status = 0U;
		uint16_t battery_status = 0U;

//		if (BQ_ReadU8(0x03, &safety_status) != HAL_OK)
//		{
//		  UART_Print("Safety Status read error\r\n");
//		  continue;
//		}
//
//
//		if (BQ_ReadU16(0x00, &control_status) != HAL_OK)
//		{
//		  UART_Print("Control Status read error\r\n");
//		  continue;
//		}
//
//
//		if (BQ_ReadU16(0x12, &battery_status) != HAL_OK)
//		{
//		  UART_Print("Battery Status read error\r\n");
//		  continue;
//		}
//
//
//		if (BQ_ReadU8(0x7F, &fet_status) != HAL_OK)
//		{
//		  UART_Print("FET Status read error\r\n");
//		  continue;
//		}

		// normal data
		data_transmit.timestamp = batt_data.timestamp;
		data_transmit.read_out_time = batt_data.read_out_time;
		data_transmit.status = 0;
		data_transmit.data_1 = batt_data.cell1;
		data_transmit.data_2 = batt_data.cell2;
		data_transmit.data_3 = batt_data.cell3;
		data_transmit.data_4 = batt_data.cell4;
		data_transmit.data_5 = batt_data.cell5;
		data_transmit.data_6 = batt_data.cell6;
		data_transmit.data_7 = batt_data.stack_voltage_raw;
		data_transmit.data_etc_1 = -batt_data.current_raw;
		if(TEMP_UNIT == 2)
		{
			data_transmit.data_etc_2 = batt_data.ext_temp_raw - 2731;
		}
		else
		{
			data_transmit.data_etc_2 = batt_data.ext_temp_raw;
		}

		UART_TransmitParsedData(&data_transmit);
		HAL_GPIO_TogglePin(LED_GPIO_Port, LED_Pin);
  }
  /* USER CODE END 3 */
}

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


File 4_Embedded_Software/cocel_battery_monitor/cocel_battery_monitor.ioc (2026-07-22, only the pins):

Mcu.UserName=STM32G031K8Ux
PA13.Signal=SYS_SWDIO
PA14-BOOT0.Signal=SYS_SWCLK
PA7.GPIO_Label=LED
PA7.Signal=GPIO_Output
PB0.GPIO_Label=ARM_SW
PB0.Signal=GPIO_Output
PB6.Signal=USART1_TX
PB9.Signal=I2C1_SDA

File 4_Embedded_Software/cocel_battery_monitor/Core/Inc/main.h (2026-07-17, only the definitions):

#define LED_Pin GPIO_PIN_7
#define LED_GPIO_Port GPIOA
#define ARM_SW_Pin GPIO_PIN_0
#define ARM_SW_GPIO_Port GPIOB

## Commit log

2026-05-29 added schematic pdf
2026-07-17 [ADD - SanghyunPark01]Embedded software prototype
    [cocel_battery_monitor Debug.cfg]
2026-07-20 DEBUG: Fixed circuit bugs - Added I2C pull-up resistors - Fixed BQ76942 REG pin bugs - Added temperature sensor
    [PowerMonitor.kicad_pcb, PowerMonitor.kicad_sch]

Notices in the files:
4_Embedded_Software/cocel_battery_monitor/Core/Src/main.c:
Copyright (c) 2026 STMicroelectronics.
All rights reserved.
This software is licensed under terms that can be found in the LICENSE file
